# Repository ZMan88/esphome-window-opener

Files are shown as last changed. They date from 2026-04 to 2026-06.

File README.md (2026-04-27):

# Window Opener

A DIY ESP32-based device that opens and closes a European tilt-and-turn window, integrated with Home Assistant via ESPHome. One actuator anchored at the bottom-hinge corner of the frame drives both tilt and turn modes, controllable as a percentage (0–100%).

**Status:** scaffolding (Phase 0). No hardware built yet. See `PLAN.md`.

If you're trying to understand what this thing physically *looks like*, start with [`docs/how-it-works.md`](docs/how-it-works.md) — plain-language walkthrough plus an annotated 3D overview.

Assembly overview — installed mechanism
Mounting geometry — front view, tilt mode, turn mode

## How it works

A tilt-and-turn window has one corner — the bottom-hinge-side corner — that stays fixed in both tilt mode (short inward tilt from the top) and turn mode (full inward swing like a door). Anchoring one end of a linear actuator at that fixed corner and the other end at the opposite sash corner means the same stroke drives both modes. The user picks the mode on the window handle; the firmware only commands position.

## Hardware (at a glance)

- **MCU:** ESP32 DevKit V1
- **Actuator (choose one at build time):**
  - 12V DC linear actuator + BTS7960 H-bridge (robust, simple)
  - NEMA17 stepper + TMC2209 + lead screw (silent, precise)
- **Power:** 12V PSU → buck to 5V for the ESP32
- **Feedback:** time-based position (with optional 10-turn pot) or step counting

Full BOM: [`hardware/BOM.md`](hardware/BOM.md). Wiring: [`hardware/wiring/`](hardware/wiring/).

## Quick start (firmware)

```
cp firmware/common/secrets.example.yaml firmware/common/secrets.yaml
# edit secrets.yaml with Wi-Fi + OTA creds
esphome run firmware/window-opener.yaml
```

Home Assistant auto-discovers the ESPHome device and exposes `cover.window_opener`.

## Repository map

- [`firmware/`](firmware/) — ESPHome YAML
- [`hardware/`](hardware/) — BOM, wiring, power
- [`mechanical/`](mechanical/) — CAD and 3D-print STLs
- [`home-assistant/`](home-assistant/) — example automations and Lovelace card
- [`docs/`](docs/) — architecture, assembly, calibration
- [`PLAN.md`](PLAN.md) — roadmap, decisions, open questions
- [`CLAUDE.md`](CLAUDE.md) — guidance for Claude Code sessions

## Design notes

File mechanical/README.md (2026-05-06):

# Mechanical design

The mechanical design is the load-bearing part of this project — the firmware only works if the geometry works. Read this before opening CAD.

## Mounting geometry

The target window (see `docs/window-spec.md`) is a European tilt-and-turn, 845 × 1325 mm, hinge on the **right**, handle on the **left**. The actuator is mounted horizontally across the top of the window:

- **Fixed end** at the **top-middle of the frame** (`x = W/2 = 422.5 mm` from the left jamb), on `cad/frame-bracket.FCStd`.
- **Moving end** on the **top edge of the sash**, `d = 120 mm` from the hinge side (`cad/sash-bracket.FCStd`).
- Both ends use **M6 or M8 ball-joint rod ends** so the actuator can swing vertically (tilt) and horizontally (turn) without binding.

Geometry — front, tilt, turn views

### Fixed-end mounting detail

The fixed-end bracket bolts to the **room-side (inside) face of the top frame rail**, not above the frame. The actuator body hangs in the room at roughly the height of the top of the window, with no interference from the ~20 mm ceiling gap above the frame.

Mounting cross-section — fixed end
Mounting cross-section — sash end

Both brackets are **190 mm wide** along the window length (into the page of the side cross-sections). That width sets the VHB + screw area available to resist torque from the actuator.

**Fixed-end bracket (top-middle of frame):**

- Hard constraint — only 20 mm of frame face is accessible. The sash covers the frame's inside face everywhere except a 20 mm strip between the sash top and the ceiling.
- The **frame top touches the ceiling** (no air gap above the frame), so there is nowhere to hook over. Mounting has to live in the 20 mm strip itself.
- **Load is comfortable.** Actuator force is along the window width, so peel bending is about the vertical axis across the full 190 mm plate width — not across the 18 mm plate height. Peel stress at stall ≈ 140 kPa, well inside standard VHB's 500 kPa limit (~3× margin).
- The `cad/frame-bracket.scad` bracket includes a 2 mm **ceiling-jam tab** at the top edge. It is an **install aid and a passive peel-resist** for edge cases (VHB aging, assembly errors) — *not* a primary load path. When the bracket is pushed up during install, the tab compresses slightly against the ceiling and holds the bracket in place while the VHB sets and screws go in.
- Load path: VHB (primary, shear + peel) → 2× M4 self-tappers into PVC (backup).
- Install: press the bracket up into the 20 mm strip (tab compresses), then screw in from the room side.

**Sash-end (moving) bracket — `docs/mounting-detail-sash.svg`:**

- The sash's room-side face is 20 mm proud of the frame, so the *entire* sash top rail is accessible.
- Plate is 190 × ~42 mm (~8000 mm²). Stall-force tensile stress ~160 kPa — 3× margin below VHB's limit. **No hook needed.**
- The 20 mm sash lip already provides most of the standoff the fixed-end bracket gets from its arm. The M6 rod-end shank threads directly through the plate; a nut on the sash side locks it. No separate arm geometry.
- Load path: VHB (primary) → 3× M4 self-tappers into the sash top rail.
- Install: peel-off VHB backing, press on, screw in. Much simpler than the fixed end.

### Why this geometry works for both modes

For an actuator to drive a rotation, neither endpoint can sit on the rotation axis — otherwise the distance between the two endpoints stays constant during rotation, and the actuator can't change the angle.

| Endpoint | On tilt axis (bottom edge)? | On turn axis (right edge)? |
|---|:-:|:-:|
| Fixed: top-middle of frame `(W/2, 0)` | off | off |
| Moving: top of sash, 120 mm from hinge `(W-120, 0)` | off | off |

Both endpoints are off both axes, so extending the actuator drives the sash open in whichever mode the handle has selected.

### Stroke–angle map (with d = 120 mm)

| State | Distance | Stroke |
|---|---:|---:|
| Closed | 302.5 mm | 0 |
| Full tilt (7°, scissor stop) | 343.1 mm | 40.6 mm |
| Full turn (90°) | 439.2 mm | 136.7 mm |
| Full turn (100°, hardstop margin) | 458.8 mm | 156.3 mm |

Target actuator: **200 mm stroke, ≥ 500 N force, 12 V DC.** Force is dominated by the turn-mode moment arm (`d = 120 mm`); tilt is gravity-assisted and needs < 20 N.

## Mode asymmetry — important

Full tilt sits at ~26% of stroke; full turn at ~78%. The same `cover.position = 50` means different window angles in the two modes. The firmware exposes raw **stroke %**; per-mode semantics live in Home Assistant (see `docs/architecture.md`). If you ever add a handle-position sensor, the firmware can remap to clean per-mode percentages — noted in `PLAN.md`.

## Ball-joint rod ends are required

In tilt mode the moving end traces a short arc around the bottom edge. In turn mode the same point traces a wide arc around the hinge side — a different plane. The actuator body must be free to swing in **two axes** at each end. Use **M6 or M8 rod-end (heim) joints** at both ends. Fixed pivots or single-axis hinges will bind in one mode, usually turn.

## Bracket design notes

- **Print in PETG or ABS**, not PLA — summer sun on the frame easily exceeds PLA's glass-transition temperature.
- Brackets mount with **VHB double-sided tape** as a reversible baseline; add self-tapping screws only after placement is confirmed (drilling into a PVC window is irreversible).
- The **tilt stay** (scissor visible in the top-left of `docs/window-photo.jpg` for the target window) lives on the handle side — keep brackets clear of its travel.
- The fixed-end bracket is on the top rail of the frame, centered. Leave ~20 mm clearance above so the actuator body can pivot up (retract side) and down (extend side) as the sash tilts.
- The sash bracket sits on the top rail of the sash, 120 mm inboard from the hinge. In turn mode it swings outward into the room; confirm nothing on the room side (curtains, blinds, shelves) is in the 90° arc.

## CAD files

- `cad/common.scad` — shared parameters (window dims, KP08 / Prusa-nut / NEMA17 dimensions).
- `cad/sash-bracket.scad` — moving-end window bracket, 120 mm from the hinge on the sash top rail.
- `cad/frame-bracket.scad` — fixed-end window bracket, top-middle of the frame.
- `cad/rig-motor-mount.scad` — lead-screw rig: motor + KP08 #1 + frame-side rod-end mount.
- `cad/rig-far-bearing.scad` — lead-screw rig: KP08 #2 holder at the far end.
- `cad/rig-carriage.scad` — lead-screw rig: Prusa-nut + LH rod-end carriage that slides on the screw.
- `cad/README.md` — install / render / print instructions.
- `stl/*.stl` and `stl/*.png` — exported printable STLs and preview renders.

### Window-side brackets

| Bracket | Preview |
|---|---|
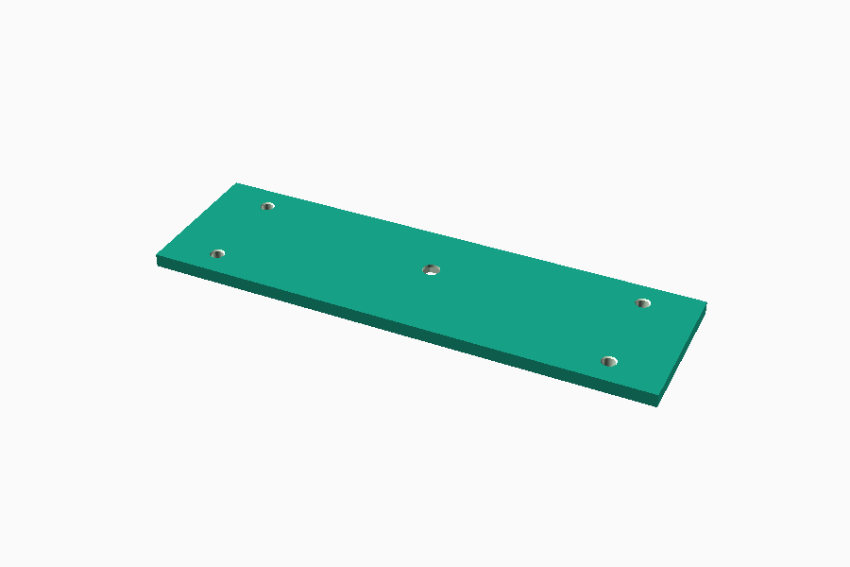
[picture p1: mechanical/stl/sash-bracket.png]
sash bracket
| Sash bracket (flat plate, 4 corner M4 + central M6 + back-face hex pocket) |  |
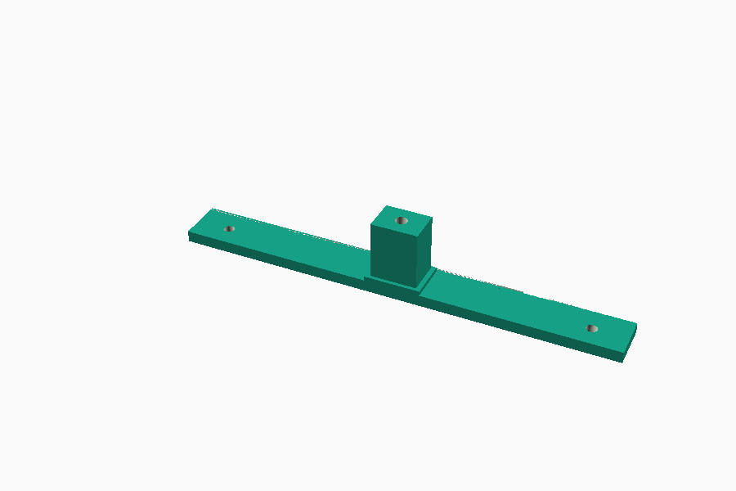
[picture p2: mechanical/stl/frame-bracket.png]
frame bracket
| Frame bracket (plate + arm + ceiling-jam tab) |  |

### Lead-screw rig (the "DIY linear actuator" between the two brackets)

| Part | Preview |
|---|---|
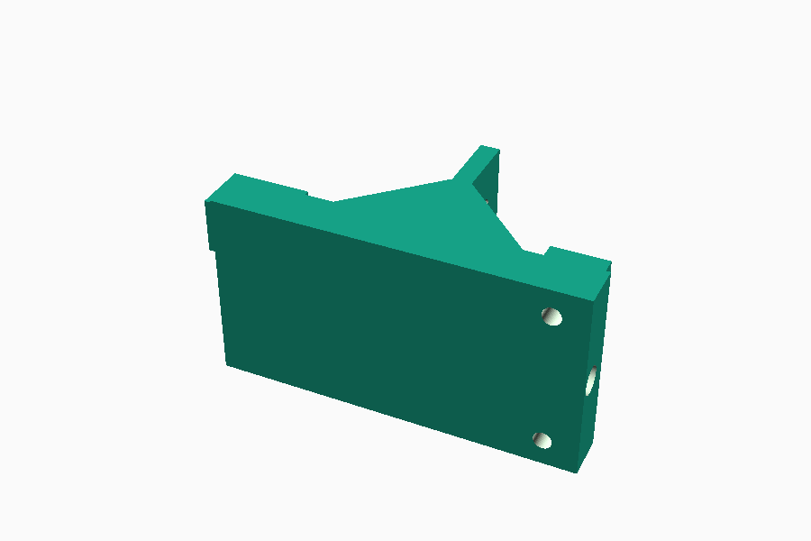
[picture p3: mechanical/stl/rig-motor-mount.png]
motor mount
| Motor mount + KP08 #1 holder + rod-end tab |  |
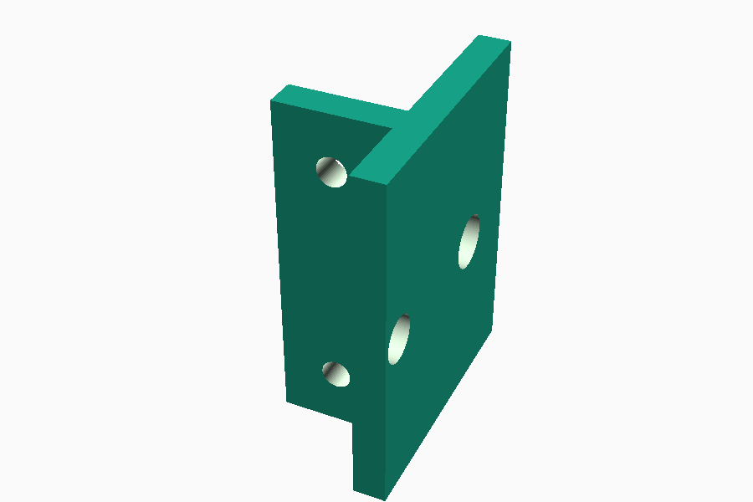
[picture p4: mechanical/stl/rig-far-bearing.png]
far bearing
| Far-end bearing block |  |
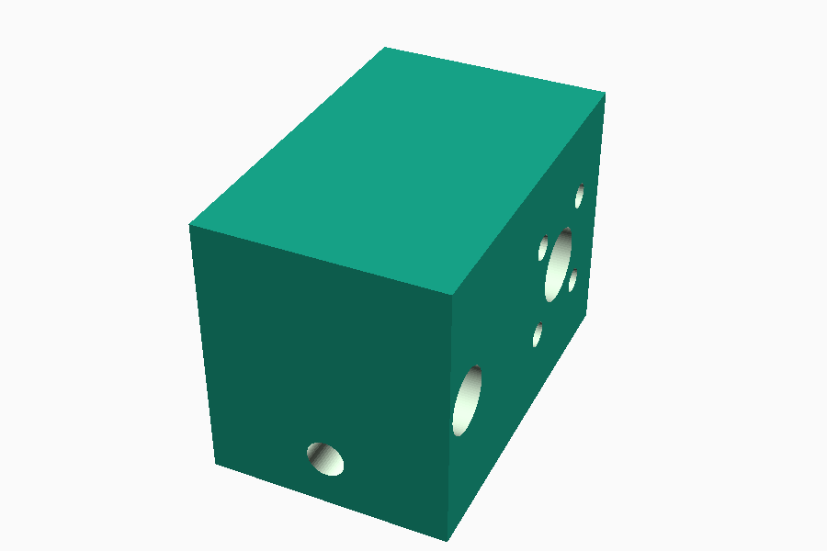
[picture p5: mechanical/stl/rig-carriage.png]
carriage
| Carriage (holds Prusa nut + LH rod-end) |  |

The rig is a self-contained linear-actuator equivalent: NEMA17 at one end drives the lead screw through KP08 #1, the screw extends to KP08 #2 at the far end, and the carriage rides along the screw via the Prusa nut. An 8 mm smooth steel rod runs parallel to the screw at a 30 mm offset to prevent the carriage from rotating with the screw — the carriage has a clearance hole through it for that rod. The motor-end of the rig has a rod-end tab that mounts to the frame bracket, and the carriage has its own rod-end mount on the bottom that connects to the sash bracket.

**Critical: rig CAD uses placeholder dimensions for the KP08 and Prusa nut at the top of `cad/common.scad`.** Verify with calipers before printing — those parts vary between manufacturers. Re-render after any `.scad` change.

Enclosure (`cad/esp32-enclosure.scad`) is not yet modelled — comes after the electronics bring-up in Phase 1.

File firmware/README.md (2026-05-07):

# Firmware

ESPHome config for the window opener. Entry point: `window-opener.yaml`.

## First-time setup

```
cp common/secrets.example.yaml common/secrets.yaml
# edit common/secrets.yaml with real values
```

Generate a fresh API encryption key and OTA password:

```
openssl rand -base64 32   # api_encryption_key
openssl rand -base64 16   # ota_password, fallback_password
```

## Build / flash

Run from the repo root, not from `firmware/`:

```
esphome config firmware/window-opener.yaml   # validate YAML only
esphome run    firmware/window-opener.yaml   # compile + flash + follow logs
esphome logs   firmware/window-opener.yaml   # tail logs from a running device
```

`esphome run` auto-detects USB vs OTA — plug in over USB the first time, then subsequent flashes go over the network.

## Switching actuator variant

Edit the `packages:` block in `window-opener.yaml`:

```yaml
packages:
  base: !include common/base.yaml
  variant: !include variants/linear-actuator.yaml   # or variants/stepper.yaml
```

Only one `variant:` line should be uncommented. Both variants expose the same HA entity (`cover.window_opener`), so no HA-side change is needed when switching.

## File layout

- `window-opener.yaml` — top-level config, variant selector
- `common/base.yaml` — Wi-Fi, API, OTA, logger, uptime
- `common/secrets.example.yaml` — template for `secrets.yaml`
- `variants/linear-actuator.yaml` — BTS7960 + time-based cover
- `variants/stepper.yaml` — TMC2209 + stepper + endstop + template cover (basic STEP/DIR, no UART)
- `variants/stepper-uart.yaml` — TMC2209 over **UART**: software-set current, live current/load/temperature exposed to HA, optional StallGuard sensorless homing. Requires two extra wires (XIAO D6 → driver RX, XIAO D7 → driver TX) and the slimcdk community external component.

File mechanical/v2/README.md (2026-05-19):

# Window Opener — v2 (motor on sash, screw on frame)

Variant of the v1 design with the actuator topology inverted: the
motor lives on the moving sash, the lead screw is anchored to the
static frame. Driving the motor rotates the screw, which threads
through a captive nut on the frame, pulling the motor (and the sash)
along with it.

v1 (in `mechanical/cad/`) remains the reference design; v2 explores
whether the inversion buys fewer parts and a simpler kinematic chain
at the cost of cable management and an exposed screw.

## How it works

```
   sash bracket                                            frame bracket
   ┌────────────┐  U-joint   ┌──────────────────────┐    ┌──────────────┐
   │ NEMA17     ├──[ ✕ ]─────┤ Tr8x8 lead screw ████├────┤ brass nut    │
   │ rigidly    │            │ rotates with motor   │    │ in 2-DOF     │
   │ on bracket │            └──────────────────────┘    │ gimbal       │
   └────────────┘                                        └──────────────┘
        │                                                       │
   bolted to sash                                          bolted to frame
   top rail at d=120 mm                                    top-middle
```

Motor spins the screw via a small U-joint. The screw passes through a
brass nut held in a 2-DOF gimbal on the frame bracket. The nut is
rotationally locked by the gimbal but free to pivot in pitch and
yaw — so the screw can swing through the angle range the sash
demands (tilt: arc in the X-Y plane; turn: arc in the X-Z plane)
while still translating through the threads.

When the motor turns clockwise the screw threads INTO the nut → screw
+ motor + sash get pulled toward the frame. Counter-clockwise →
pushed away.

## Components

| # | Part | Source |
|---|---|---|
| 1 | NEMA17 motor (LDO 42STH48-1684MAC) | reused from v1 |
| 2 | Tr8x8 lead screw, ~500 mm | reused from v1 (longer; see stroke notes) |
| 3 | Prusa MK3 brass nut | reused from v1 |
| 4 | Ø5–Ø8 single Cardan U-joint, L=35 mm, OD=14 mm | QUARKZMAN / Aopin pin-and-block style, 45° max angle, 2× M4 set screws per bore. Listing: Amazon DE `B0DTTRBWLK` (QUARKZMAN, 2-pack with wrench and spare grub screws). Equivalent Amazon US `B08V92X8M8` (Aopin). |
| 5 | Cross pins for gimbal (Ø3 × 25 mm) | sourced (steel dowel) |
| 6 | sash-motor-mount | printed — `cad/sash-motor-mount.scad` |
| 7 | frame-nut-gimbal | printed — `cad/frame-nut-gimbal.scad` |

What's gone vs v1: rig-motor-mount, rig-far-bearing, rig-carriage, 2×
KP08 pillow blocks, anti-rotation rod, both rod-ends. v2 needs 2
printed parts where v1 needed 5.

## Mechanical considerations

**Cantilevered motor.** NEMA17 ≈ 280 g hangs off the sash bracket's
M3 mounting holes. The bracket has a small "floor" that the motor
body rests on (mirror of v1's rig motor mount) so the four M3 bolts
don't carry the full bending moment.

**Exposed lead screw.** Most of the screw's length is in free air
between the brackets. A flexible sleeve over the screw (corrugated
plastic, cable-management style) is recommended for dust + accidental
contact.

**Motor cable on the moving part.** Cable runs from the controller
(static, on the frame or wall) to the motor (moving, on the sash).
Needs strain relief at the bracket and slack management through the
sash's motion range — a small drag chain or a service loop pinned at
the hinge corner is usually enough.

**Gimbal anti-roll.** The brass nut MUST be rotationally locked
relative to the frame bracket. If the nut can spin freely with the
screw, no axial translation happens. Both gimbal pins are perpendicular
to the screw axis, so they prevent roll while allowing pitch + yaw.

**Stroke length.** Effective max screw-to-anchor distance under full
tilt is ≈ 450 mm (see `docs/window-spec.md`); under 90° turn it's
≈ 440 mm. Use a 500 mm screw with the nut at mid-travel when closed,
giving ~150 mm of stroke each way.

## Range of motion at the gimbal

| Mode | Frame-to-sash anchor angle change |
|---|---|
| Closed → full tilt (~15°) | screw pitch + yaw both vary, max ~25° from horizontal |
| Closed → 90° turn | screw yaw varies by ~25° in the horizontal plane |

A 2-DOF gimbal with ±30° pin clearance handles both, and the
sourced 45°-max U-joint covers the motor-shaft side with ~20°
headroom.

## U-joint install notes

- **Motor end (5 mm bore):** seat both M4 set screws on the LDO 42STH48's
  D-flat (15 mm long × 4.5 mm deep, declared in `common.scad`). Loctite
  blue on the threads — the joint sees full motor torque and constant
  vibration.
- **Lead-screw end (8 mm bore):** Tr8 has no flat. File a small flat
  (~6 mm × 0.3 mm) on the smooth end-section of the screw for the
  set screws to bite. Loctite there too.
- **Backlash:** budget 1–2° of rotational play in the joint. At the
  Tr8 lead this is < 0.05 mm of axial slop — invisible at the percent
  resolution the HA `cover` entity exposes.
- **Velocity-ratio variation:** a single Cardan introduces ±10% RPM
  ripple at 25° angle. Irrelevant for a slow window cover, but if
  position holding ever feels jittery at the extremes, the upgrade is
  a double-Cardan or a constant-velocity joint of the same family.

## Render

```
cd mechanical/v2/cad
openscad --export-format binstl -o ../stl/sash-motor-mount.stl  sash-motor-mount.scad
openscad --export-format binstl -o ../stl/frame-nut-gimbal.stl  frame-nut-gimbal.scad
openscad --colorscheme=Nature --imgsize=900,600 -o ../stl/sash-motor-mount.png sash-motor-mount.scad
openscad --colorscheme=Nature --imgsize=900,600 -o ../stl/frame-nut-gimbal.png frame-nut-gimbal.scad
openscad --camera=350,-350,500,250,0,-15 --imgsize=1600,900 --colorscheme=Tomorrow \
         -o ../stl/v2-assembled-iso.png  v2-assembled.scad

# Single mesh STL of the whole assembly (viewing aid, not for slicing —
# the hardware stand-ins for motor / U-joint / screw / nut are baked in)
openscad --export-format binstl -o ../stl/v2-assembled.stl v2-assembled.scad
```

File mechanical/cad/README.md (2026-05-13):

# CAD

Parametric OpenSCAD sources for the two brackets. Text-based so the
geometry is diffable in git.

## Files

- `common.scad` — shared parameters (hole sizes, bracket width, etc.).
  Edit here to update both brackets at once.
- `sash-bracket.scad` — moving-end bracket, attaches to the sash top rail.
- `frame-bracket.scad` — fixed-end bracket, attaches to the 20 mm strip of
  frame face between the sash top and the ceiling.
- `rig-motor-mount.scad` — printed L-bracket carrying the NEMA17 + KP08 #1.
- `rig-far-bearing.scad` — printed L-bracket carrying KP08 #2 + anchor for
  the anti-rotation rod.
- `rig-carriage.scad` — printed block riding on the lead screw via the
  Prusa MK3 brass nut; holds the LH M6 rod-end on its bottom face.
- `rig-assembled.scad` — **assembly preview**. Includes the parts above
  plus stylised stand-ins for the motor / screw / KP08 / brass nut / rod-ends.
  Render with the camera invocations below to get the three views in
  `../stl/rig-assembled-{top,side,iso}.png`. The standalone parts'
  STLs/PNGs remain the source-of-truth for slicing.

## Install OpenSCAD

macOS: `brew install --cask openscad`  ·  [download page](https://openscad.org/downloads.html)

## Render STLs

```
cd mechanical/cad
openscad --export-format binstl -o ../stl/sash-bracket.stl  sash-bracket.scad
openscad --export-format binstl -o ../stl/frame-bracket.stl frame-bracket.scad
```

`--export-format binstl` emits binary STL (`~30–130 KB`) instead of
ASCII (`~10× larger`). Sliced STLs from the same `.scad` will be
identical between machines.

Optional preview render (PNG, no slicer needed):

```
openscad --colorscheme=Nature --imgsize=900,600 -o ../stl/sash-bracket.png  sash-bracket.scad
openscad --colorscheme=Nature --imgsize=900,600 -o ../stl/frame-bracket.png frame-bracket.scad
```

## Assembled view

```
cd mechanical/cad
# Top  (orthographic, looking straight down)
openscad --camera=150,800,0,150,-25,0   --imgsize=1600,500 --colorscheme=Tomorrow --projection=ortho \
         -o ../stl/rig-assembled-top.png  rig-assembled.scad
# Side (orthographic, looking along the rig's depth axis)
openscad --camera=150,-25,800,150,-25,0 --imgsize=1600,650 --colorscheme=Tomorrow --projection=ortho \
         -o ../stl/rig-assembled-side.png rig-assembled.scad
# Isometric (perspective)
openscad --camera=600,400,500,150,-25,0 --imgsize=1600,900 --colorscheme=Tomorrow \
         -o ../stl/rig-assembled-iso.png  rig-assembled.scad
# Single mesh of the whole rig (printable parts + hardware stand-ins)
openscad --export-format binstl -o ../stl/rig-assembled.stl rig-assembled.scad
```

The assembled STL is a visualization aid only — it includes the off-the-shelf
stand-ins (motor, screw, KP08s, nut, rod-ends) and is not meant for slicing.
For printing, use the individual part STLs (`rig-motor-mount.stl`, etc.).

The repo ships with the current STLs and PNGs in `mechanical/stl/`;
re-render after any change to the `.scad` sources.

> **macOS note:** the default `brew install --cask openscad` ships an
> Intel-only build that fails Gatekeeper on Apple Silicon. Use
> `brew install --cask openscad@snapshot` instead — it's the
> dev/nightly build with native Apple Silicon support.

## Print settings (starting point)

- Filament: PETG or ABS (don't use PLA — sun on the window frame can
  exceed its glass-transition temperature).
- Layer: 0.2 mm.
- Walls: 4 perimeters.
- Infill: 40 % gyroid.

### Orientation

- **`frame-bracket.scad`** — flat on the bed, **back face (VHB side) down**.
  The arm prints upward, no supports needed.
- **`sash-bracket.scad`** — flat on the bed, **back face UP**.
  The hex pocket for the M6 nut is on the back face; printing back-up
  means the pocket prints as a clean cavity. The M4 holes go all the
  way through, so orientation does not affect them.

## Post-print

- **Frame bracket:** tap the M6 hole at the end of the arm with an M6 ×
  1.0 hand tap. The hole is printed at 5.0 mm (tap-drill size).
- **Sash bracket:** *no tapping*. The M6 hole is a clearance through-hole
  (6.5 mm). The rod-end shank passes through and is locked with an M6
  nut sitting flush in the hex pocket on the back face.
- Apply VHB tape (3M 4950 or 5952) to the back face of both brackets
  before installing.
- Attach with M4 × 16 self-tappers into the PVC after positioning.

### Sash bracket — rod-end mounting in detail

Standard M6 male rod-ends usually have a 30 mm threaded shank. After:

1. drop the M6 nut into the hex pocket on the bracket's back face,
2. pass the rod-end shank through from the front,
3. thread it down into the nut and tighten,

…the tail of the shank will protrude ~20 mm past the back of the bracket.
You'll need to **drill a Ø6.5 × 25 mm pilot hole into the sash top rail**
where the shank tail will sit. PVC sash profiles have hollow chambers
inside, so you're drilling into air — no problem.

If you'd rather avoid drilling the sash, source a **short-shank rod-end**
(15–20 mm thread) instead; the tail then ends inside the bracket plate.

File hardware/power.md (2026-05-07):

# Power design

Single 12V mains PSU powers both the actuator and the ESP32. The ESP32 runs from 5V via a buck converter on the same 12V rail.

## Sizing the PSU

- **Linear actuator variant.** Size to roughly 1.5× the actuator's stall current. A typical 150 N / 50 mm-s actuator stalls at ~3 A, so a 5 A / 12 V / 60 W PSU is a safe baseline. Verify against the specific actuator's datasheet before ordering.
- **Stepper variant.** NEMA17 at 1.5 A/coil with both coils energised ≈ 3 A peak, but TMC2209 chopper drops typical draw well below that. A 3 A / 12 V / 36 W PSU is usually fine; go to 5 A if you're running near the stepper's rated current.

Headroom matters more than efficiency — the 12V rail also feeds the ESP32 buck.

## Protection

- **5 A inline blade fuse** on the 12V+ lead out of the PSU, close to the PSU (not close to the driver). Motor fault or stuck carriage should pop the fuse, not melt wires.
- **TVS diode (1.5KE18CA or similar)** across the actuator motor leads to snub inductive flyback. Linear actuator variant only — TMC2209 handles its own flyback.
- **100 µF electrolytic cap** across `VM`/`GND` at the TMC2209. Stepper variant only — *required*, not optional.
- The XIAO buck converter (MP1584 mini, or LM2596 if you prefer the bigger module) is fed from the same 12V rail, after the fuse. If the fuse blows, the XIAO loses power too — this is intentional so HA flags the outage.

## Grounding

All grounds (PSU −, driver GND, ESP32 GND, endstop GND) tie together at a single star point at the PSU. Do **not** daisy-chain grounds through the driver — motor return currents on a shared wire will introduce noise on the ESP32 GND.

## What's not here (yet)

- **No battery backup.** If mains drops, the window holds its last physical position. Intentional for v1.
- **No mains switch on the device.** Unplug the PSU if you need to service.
- **No opto-isolation** between ESP32 and driver. Both drivers referenced here are happy with direct 3.3V logic, but if you switch to a high-side driver or a 24V setup, add an isolator.

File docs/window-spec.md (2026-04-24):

# Target window — physical specification

These measurements drive the actuator sizing and bracket geometry. Re-measure if the build targets a different window.

| Reference | Photo |
|---|---|
| Front view, tilted | [`photos/window-tilted.jpeg`](photos/window-tilted.jpeg) |
| Looking up at the tilted gap | [`photos/bottom_up_view.jpeg`](photos/bottom_up_view.jpeg) |
| Right-side profile (hinge side, showing reveal) | [`photos/side_view.jpeg`](photos/side_view.jpeg) |

Observations from the photos:

- Frame profile is ~70 mm deep; room-side face is clean and accessible for bracket mounting.
- Wall reveal on the hinge side is ~15–20 cm — the sash has ample clearance to swing past 90° into the reveal in turn mode.
- Fly screen is on the **outside** of the sash; it does not constrain room-side mounting.
- Top-of-frame to ceiling gap is ~20 mm — irrelevant because the actuator mounts on the frame's room-side face, not above it.
- No tilt-stay (scissor) at the top-middle; the tilt limit is set by the hinges, leaving the top-middle clear for the fixed-end bracket.

## Measured

| Parameter | Value | Notes |
|---|---:|---|
| Sash width (W) | 845 mm | inside of frame, horizontal |
| Sash height (H) | 1325 mm | inside of frame, vertical |
| Tilt gap at top | 160 mm | distance from frame plane to sash face at full tilt |
| Turn gap at hinge side (at 90°) | 25 mm | sash-to-frame offset when fully turned |
| **Sash lip (room-side protrusion past frame)** | **20 mm** | the sash's room-side face sits 20 mm forward of the frame's inside face |
| **Sash thickness** | **80 mm** | full depth of the sash profile (outside face to room-side face) |
| **Frame depth** | **80 mm** | full depth of the frame profile |
| **Frame rail width (top, visible-plus-hidden)** | **80 mm** | total top-rail height from the outer edge to the inner edge; the sash covers 60 mm of this |
| **Frame face visible above sash** | **20 mm** | the sash covers the rest of the frame's inside face; bracket must fit in this 20 mm strip between sash top and ceiling |
| Hinge side | right | turn pivot axis = right edge |
| Handle side | left | mid-height |
| Tilt stay location | top-left (handle side) | visible in photo; mount clear of this |
| Turn hardstop | >90° | plan for ~100° headroom |

## Derived

| Derived quantity | Value | How |
|---|---:|---|
| Max tilt angle (θ_max) | ~7° | `arcsin(160 / 1325)` |
| Center of sash from turn pivot | 423 mm | `W / 2` |
| Sash weight (estimated) | 15–25 kg | double-glazed, PVC-framed, typical |

## Design constants used elsewhere in the repo

| Constant | Value | Where used |
|---|---:|---|
| `d` (moving-anchor offset from hinge) | 120 mm | `mechanical/README.md`, bracket CAD |
| Fixed anchor position | `(W/2, 0)` = top-middle of frame | `mechanical/README.md` |
| Moving anchor position | `(W - d, 0)` = top edge of sash, 120 mm from hinge | `mechanical/README.md` |
| Bracket width (both brackets) | 190 mm | along the window length, limits torque on mounting |

## Required actuator spec

| Parameter | Value | Reason |
|---|---:|---|
| Stroke | ≥ 160 mm (use 200 mm) | full-turn stroke plus margin |
| Force | ≥ 500 N | worst-case friction torque / moment arm at `d = 120 mm` |
| Voltage | 12 V DC | matches PSU choice |
| Speed | 15–25 mm/s | full stroke in 8–14 s (acceptable) |

## Stroke-to-angle table (for reference)

With `d = 120 mm`:

| Actuator stroke | Tilt angle | Turn angle |
|---:|---:|---:|
| 0 mm | 0° (closed) | 0° (closed) |
| 20 mm | ~5° | ~22° |
| 40 mm | ~7° (hardstop) | ~37° |
| 80 mm | — (stalled) | ~64° |
| 120 mm | — | ~84° |
| 137 mm | — | 90° |
| 160 mm | — | ~100° |

**Interpretation:** the same actuator stroke maps to different window angles depending on mode. Firmware exposes raw stroke %; HA automations translate to tilt or turn percentage if needed. See `docs/architecture.md`.

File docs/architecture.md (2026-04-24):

# Architecture

## Why one actuator drives both modes

A European tilt-and-turn window has two pivot axes that intersect at the bottom-hinge corner. That corner is the only point on the sash that **does not move** in either mode. Anchoring one end of a linear actuator at that corner and the other end at the diagonally-opposite sash corner means:

- In tilt mode: extending the actuator pushes the top of the sash inward (tilt opens).
- In turn mode: extending the actuator pushes the opposite side of the sash inward (turn opens).

The two arcs are in different planes, which is why both ends of the actuator need ball-joint rod ends — see `mechanical/README.md`.

The firmware is kept mode-agnostic: it commands a stroke position in 0–100 %. Whichever mode the user has selected on the window handle determines what that stroke does. This keeps the firmware, the HA integration, and the calibration data simple — one position scale, one `cover` entity.

## Software stack

```
Home Assistant
       │  (native ESPHome API, encrypted)
       ▼
     ESP32 ── ESPHome firmware (firmware/window-opener.yaml)
       │      - cover entity state machine
       │      - variant package (linear or stepper)
       ▼
  Motor driver ── Actuator
 (BTS7960 / TMC2209)
```

HA sees one entity: `cover.window_opener` with `position` 0–100. It does not know or care which actuator variant is flashed or which window mode the handle is in.

## Position tracking

- **Linear-actuator variant:** ESPHome's `cover.time_based` platform interpolates position from commanded duration. Cheap, no extra hardware. Drifts after repeated partial moves — full open/close periodically re-syncs the estimate. An optional 10-turn pot on GPIO35 upgrades this to closed-loop.
- **Stepper variant:** step counting after homing against a closed-side endstop. Exact, but the device reports `unknown` until the first homing sweep completes on boot.

## Safety model

- New movement commands pre-empt in-flight ones.
- Stall or obstruction → stop and hold. No auto-retry. HA surfaces the stuck state so a human can intervene.
- On boot: position unknown → HA cover state `unknown` → first command triggers homing.
- The window handle is the physical manual override. Turning the handle mid-travel doesn't hurt anything — the sash disengages from whichever pivot path it was on.

## What's explicitly out of scope for v1

- Battery backup.
- On-device pushbuttons.
- Rain / CO₂ sensors on the device itself (HA handles these).
- Multi-window coordination.
- Remote web UI outside of HA.

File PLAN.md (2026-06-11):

# Window Opener — Roadmap & Decision Log

## Context

DIY opener for a European tilt-and-turn window, ESP32 + ESPHome + Home Assistant. A single actuator anchored at the bottom-hinge-side corner drives both tilt (short arc) and turn (long arc) modes — the user pre-selects the mode via the window handle, the firmware commands only a 0–100% position. Tilt is the primary case; turn must work but is secondary.

## Locked decisions

- **MCU:** Seeed Studio XIAO ESP32-C6 — chosen for forward-compatibility with Matter / Thread later if desired, plus the smaller form factor
- **HA integration:** ESPHome, one `cover` entity with position 0–100 (native API; Matter is a future option)
- **Mounting:** fixed end at top-middle of frame, moving end on top edge of sash 120 mm from hinge, ball-joint rod ends at both ends
- **Actuator:** **stepper + lead screw** (Variant B) — committed late April 2026; parts ordered, see `docs/build-log.md`
- **Power:** 12V mains PSU → buck to 5V for the ESP32; no battery backup in v1
- **Manual override:** window handle (no device buttons in v1)

## Phases

- [x] **Phase 0 — Scaffolding.** Repo structure, docs, base firmware YAML, BOM, wiring templates. (This PR.)
- [x] **Phase 1 — Bench prototype.** ESP32 + driver + actuator on a bench jig. Home Assistant discovers `cover.window_opener`. % travel works against a dummy load. ✅ Passed 2026-05-08 with `variants/stepper.yaml` (basic STEP/DIR).
- [ ] **Phase 1.5 — UART upgrade (optional).** Add two wires to the driver, switch to `variants/stepper-uart.yaml`, verify current/load/temperature show up as HA sensors. Replaces the Vref pot with software current control.
- [ ] **Phase 2 — Tilt on real window.** Print brackets, mount on the frame, tune stroke calibration for tilt. Stall detection dialed in.
- [ ] **Phase 3 — Turn validation.** Verify the same mount drives turn mode without binding; measure max stroke actually used.
- [ ] **Phase 4 — Polish.** Safety edge cases, HA automations, Lovelace card, enclosure, OTA workflow.

## Decision log

Append entries as decisions get made. Format: `YYYY-MM-DD — decision — reason.`

- 2026-04-24 — Anchor actuator at bottom-hinge-side corner — single fixed point across both modes; one stroke drives both. **SUPERSEDED 2026-04-24** (see below).
- 2026-04-24 — Defer final actuator choice (linear vs stepper) to build time — dictated by parts availability, and ESPHome packages make the swap cheap.
- 2026-04-24 — Tilt takes priority over turn in firmware/UX trade-offs — tilt is the everyday ventilation case.
- 2026-04-24 — **Corrected mounting geometry: fixed end at top-middle of frame, moving end on top rail of sash 120 mm from hinge.** The earlier "bottom-hinge corner" plan was wrong: that point sits on both pivot axes, so the actuator distance is conserved in both modes — it couldn't actually drive anything. Both new endpoints are off both axes. Reason: kinematic analysis during design review.
- 2026-04-24 — Target window measured: W=845, H=1325, max tilt ≈ 7°, turn hardstop > 90°. See `docs/window-spec.md`.
- 2026-04-24 — Actuator spec: 12 V, 200 mm stroke, ≥500 N. Stroke driven by 90°+ turn; force by friction torque over a 120 mm moment arm.
- 2026-04-24 — Accept mode-asymmetry in firmware v1: `cover` reports raw stroke %, not per-mode %. Tilt full = ~26%, turn full = ~78%. HA handles mode semantics. A handle-position sensor could remap per mode later — not in v1.
- 2026-04-29 — Variant B (stepper + Tr8x8 lead screw) committed. Parts ordered (LDO 0.9° NEMA17, BIGTREETECH TMC2209 V1.3 ×2, KP08 ×2, Tr8x8 nuts ×3, lead screw 400 mm, 5→8 couplers, M6 rod-ends, LM2596). See `docs/build-log.md`.
- 2026-04-29 — **MCU swapped to ESP32-C6** (already in user's drawer). Kept ESPHome with native API for v1; the C6 keeps Matter/Thread on the table for a future migration. Required: framework switch from `arduino` to `esp-idf`, GPIO remap 25/26/27/34 → 4/5/6/7.
- 2026-05-06 — Specific board confirmed: **Seeed Studio XIAO ESP32-C6** (smaller than the DevKitC-1, only 11 GPIOs broken out). GPIO remapped 4/5/6/7 → 1/2/21/19, exposed as XIAO labels D1/D2/D3/D8. Pin assignment: D1=DIR, D2=STEP, D3=EN, D8=endstop.
- 2026-05-08 — Phase 1 bench-test passed (motor moves on command via HA). Added `variants/stepper-uart.yaml` for the UART-driven upgrade: motor current set in software, current/load/temperature surfaced as HA sensors, StallGuard available. The BTT V1.3 has buffered TX/RX (verified by multimeter — no continuity), so UART wires are direct cross-connection (XIAO D6 ↔ driver RX, XIAO D7 ↔ driver TX) with no series resistor needed.
- 2026-06-05 — **Firmware feature pass on `stepper-uart.yaml`** (now the active variant in `window-opener.yaml`):
  - **Closed detection via the window's own contact sensor imported from HA** (`closed_sensor_entity` substitution), not the printed D8 switch. The D8 endstop is **not installed at the moment** — its block is left commented, ready to OR back in. Reason: v2 mechanical has no carriage to mount the switch on yet, and the window already has a contact sensor. Trade-off: homing now depends on the HA connection.
  - **Lock** (`lock.window_lock`): drives fully closed then clamps at a firmer hold current (`lock_hold_current`, default 900 mA); refuses open/position commands while locked (closing still allowed). The manual handle remains the real mechanical lock. Lock state persists across reboot (re-homes then re-clamps on boot).
  - **Free-wheel** (`switch.window_freewheel`): releases the coils (`tmc2209.currents` `standstill_mode: freewheeling`, 0 mA hold) so the sash is hand-movable. (Avoids `tmc2209.enable/disable`, whose slimcdk `ActivationAction` fails to compile under ESPHome's 2026-04 TemplatableFn change.) Move-detection: a transition of the closed signal while free-wheeling marks position unknown → next command re-homes first. Limitation: a bare TMC2209 has no rotor feedback, so hand-movement that never crosses the closed sensor can't be detected (keeps last position). Encoder would fix this — deferred.
  - **Open-end** = StallGuard hard-stop (DIAG on D9): a stall while opening reports position = full stroke; a stall while closing is treated as an obstruction (stop + hold, no retry). Inert until SGTHRS is tuned in Phase 3.
  - **Switchable end-detection** (added 2026-06-06): `homing_mode: contact | sensorless` substitution (in `window-opener.yaml`). `contact` = home closed from the HA contact, open by calibrated step count (StallGuard = obstruction backstop). `sensorless` = no contact: ram closed at a gentle `homing_current` until StallGuard trips, and *learn* the open end from the opening-direction stall into a runtime `g_full_stroke`. Sensorless requires a tuned `stall_threshold` (SGTHRS > 0). Kept switchable so both can be compared on the real rig before committing — sensorless rams the stops every home (wear) and can't distinguish obstruction from end, so contact is the default/recommended. Position % is relative to `g_full_stroke` (fixed in contact, learned in sensorless — do one full open after homing to learn it).
  - **Homing**: passive on boot (no auto-motion — a power blip won't slam an open window shut). Position reads `unknown` until the closed contact reports shut (zeroes in place) or the first move triggers a homing sweep. Locked state is the exception: it actively drives closed on boot to re-clamp. CLAUDE.md "unknown until homed" invariant now actually enforced.

## Open questions

- License choice (placeholder MIT).
- 3D-print material for brackets — PETG vs ABS (sun/heat resistance).
- ~~Do we want an `esphome` `switch` for "home now" on boot, or keep homing fully automatic?~~ **Resolved 2026-06-05, revised 2026-06-11:** homing is automatic (passive on boot, and before any move when position is unknown). A manual **"Home now (drive to closed)"** button was added 2026-06-11 — `move_to` only auto-homes when position is unknown, so on-demand re-homing needed an explicit trigger.
- Free-wheel hand-movement that never crosses the closed sensor isn't detectable without rotor feedback — add a magnetic encoder (e.g. AS5600 on the screw) if per-mm position must survive manual moves. Deferred.
- Stall detection threshold — decide empirically in Phase 1.
- Handle-position sensor (reed switch) to detect tilt vs turn mode — if added, firmware can remap `cover.position` per mode for clean HA UX. Defer to v1.5.
- Exact sash weight — estimated 15–25 kg; confirm with a luggage scale before final actuator purchase.

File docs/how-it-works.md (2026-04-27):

# How it works — visual walkthrough

This page is the "I just want to picture the thing" guide. The other docs are the source of truth, this one is the orientation map.

## The 30-second version

You bolt **two small brackets** to the top of the window — one to the **frame** (which doesn't move), one to the **sash** (the part that swings). A **12 V linear actuator** stretches between them like an arm. When the actuator extends, it pushes the sash open. When it retracts, it pulls the sash closed. An ESP32 nearby drives the actuator and talks to Home Assistant.

That's the whole mechanism. Everything else is detail.

Isometric overview

## The pieces

There are only six things to get straight in your head:

| Piece | What it is | Where it lives |
|---|---|---|
| **The frame** | Doesn't move. The fixed border of the window. | Built into the wall. |
| **The sash** | Moves. Holds the glass. | Inside the frame opening; protrudes 20 mm into the room. |
| **Frame bracket** | Small 3D-printed plate (red in the diagrams) | Glued + screwed to the **room-side face of the frame**, top-middle. |
| **Sash bracket** | Same idea, slightly different shape | Glued + screwed to the **room-side face of the sash**, near the hinge (120 mm from the right edge). |
| **Actuator** | A 200 mm 12 V motorised piston. | Hangs horizontally between the two brackets, just in front of the top of the window. |
| **ESP32 box** | The brains | Mounted on the frame near the fixed bracket. Wires go to the actuator and to a 12 V power supply. |

## How the brackets connect to the actuator

Each bracket holds an **M6 rod-end** — a small ball-joint. The actuator's two ends bolt onto these rod-ends. Because both ends of the actuator can pivot freely (that's what "ball joint" means), the actuator can swing through the wide arcs that tilt and turn require without binding.

Picture it like an arm with shoulder joints at both ends.

## How tilt works

1. You turn the window handle to the **tilt** position.
2. The handle releases the side latches but keeps the bottom hinged.
3. From Home Assistant (or an automation), you say "tilt 50%".
4. The ESP32 commands the actuator to extend partway.
5. The actuator pushes the sash bracket forward.
6. Because the sash is hinged at the bottom, the **top of the sash swings inward** into the room — exactly like the photo you sent.

To close: the actuator retracts, pulls the sash back to flush, the gravity in the seal does the rest.

## How turn works

Same actuator, same brackets, different latch position on the handle:

1. You turn the window handle to the **turn** position (handle points sideways).
2. The handle releases the bottom hinge and engages the side hinges.
3. From Home Assistant, "turn 80%".
4. The actuator extends.
5. The sash bracket is near the hinge side, so a relatively short extension at that point swings the **opposite (handle) side of the sash into the room**, like opening a door.

The same actuator stroke does both because both anchor points were chosen carefully (`docs/geometry.svg` has the math) so neither anchor sits on a pivot axis. If either did, the actuator would jam in that mode.

## The most important constraint

The frame bracket has only **20 mm of frame face** to grab onto, because the sash protrudes 20 mm forward of the frame and covers everything below that strip. The bracket plate is therefore short and wide — 190 × 18 mm — and uses a **compressible tab** at the top that wedges against the ceiling during install. The sash bracket has the entire sash face to work with, so it's a bigger, simpler plate.

See:
- [`mounting-detail.svg`](mounting-detail.svg) — the frame bracket in cross-section
- [`mounting-detail-sash.svg`](mounting-detail-sash.svg) — the sash bracket in cross-section
- [`geometry.svg`](geometry.svg) — three views (front, tilt, turn) showing the macro layout

## How to read the existing diagrams

| Diagram | Drawing convention | Why it looks weird |
|---|---|---|
| `geometry.svg` panel 1 (Front) | Like a photo of the window from inside the room | This is the "normal" view — actuator is the diagonal grey bar |
| `geometry.svg` panel 2 (Tilt) | Vertical slice through the side, the wall is on the left | The actuator looks short because it's been rotated downward as the sash tilted |
| `geometry.svg` panel 3 (Turn) | View from above, looking down | The window opens away from the wall, into the room (downward in the diagram) |
| `mounting-detail.svg` | Vertical slice cut sideways through the top of the frame | "Outside" is on the left, "room" is on the right — the actuator body extends out of the page |
| `mounting-detail-sash.svg` | Same as above, but cut through where the sash bracket lives | The actuator body extends out of the page, going toward the fixed bracket |

## Order of build

Once parts arrive, the build order is:

1. **Bench-test the electronics first.** ESP32 + driver + actuator on the desk, no window. Confirm Home Assistant sees `cover.window_opener` and that "open" / "close" / "set position" actually move the actuator. (This is Phase 1 in `PLAN.md`.)
2. **Print both brackets** from `mechanical/cad/*.scad`. Tap the M6 holes.
3. **Dry-fit on the window.** Tape the brackets in position before any glue or screws — measure twice, drill once.
4. **Mount the actuator.** Screw the rod-ends onto the actuator first, then onto the brackets.
5. **Tilt-only first.** Run a few full tilt cycles before trying turn — turn has more inertia and a wider error margin.
6. **Calibrate.** `docs/calibration.md` covers this.

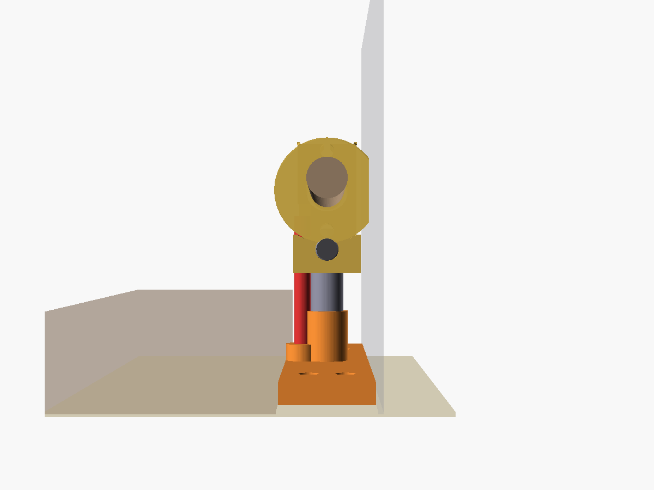
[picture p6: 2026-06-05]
mechanical/v2/cad/sketches/option3-side.png

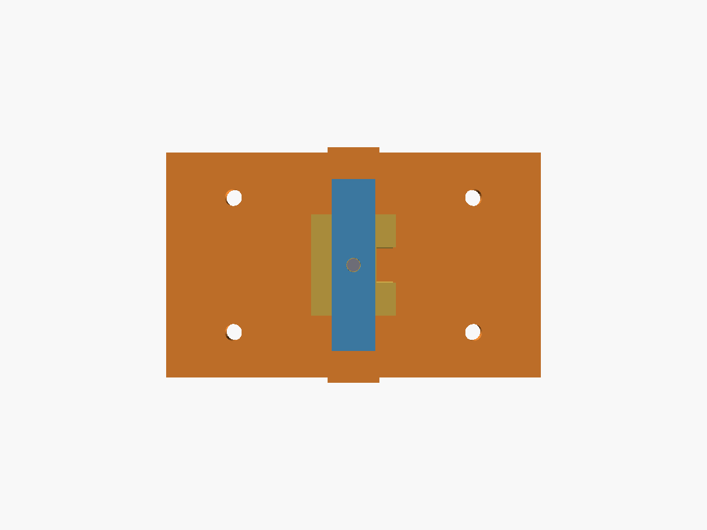
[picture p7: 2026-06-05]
mechanical/v2/stl/frame-nut-gimbal.png

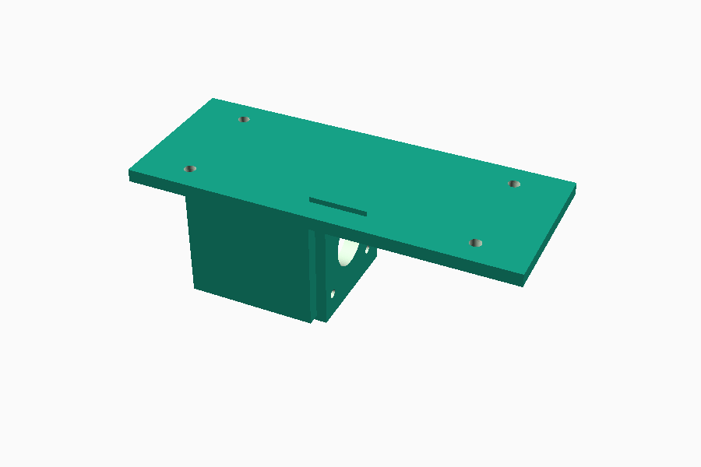
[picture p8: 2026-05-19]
mechanical/v2/stl/sash-motor-mount.png

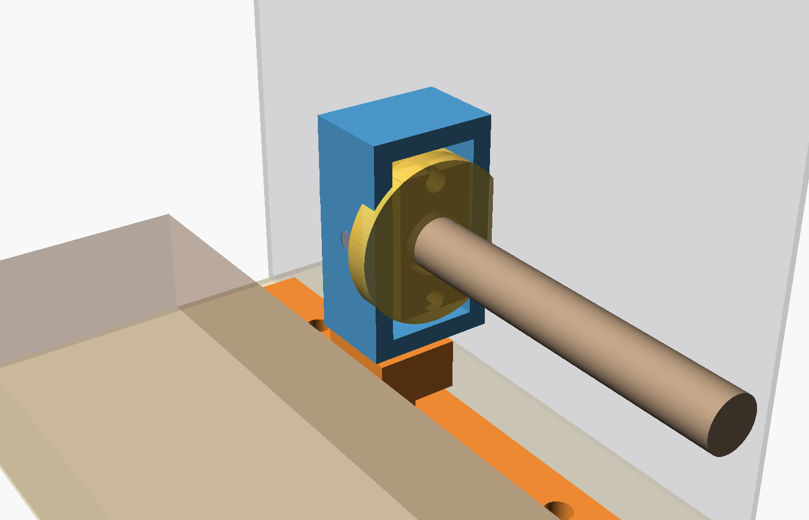
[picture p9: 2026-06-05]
mechanical/v2/cad/sketches/option1-zpivot.png

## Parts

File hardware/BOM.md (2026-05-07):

# Bill of Materials

Romanian online sources are listed first; international fallbacks (AliExpress, Amazon) where the part is uncommon locally. Prices are rough April 2026 estimates and should be re-verified at order time.

Pick **one** actuator track (Variant A or B), then add the common parts and the parts for that variant.

## Common to both variants

| Qty | Part | Source | ~RON | ~EUR |
|---:|---|---|---:|---:|
| 1 | **ESP32-C6 DevKitC-1** (Wi-Fi 6, BT 5 LE, Thread/Zigbee) | [optimusdigital.ro ESP32 boards](https://www.optimusdigital.ro/358-placi-cu-esp32) · AliExpress / Amazon for the official Espressif kit | 50–80 | 10–16 |
| 1 | 12V DC power supply, 60W / 5A, plastic case | [webled.ro YDS 60W](https://webled.ro/sursa-alimentare-yds-12v-5a-60w-cu-fir-carcasa-plastic/) · [led-box.ro 60W](https://led-box.ro/products/sursa-alimentare-5a-60w-12v) | 60–100 | 12–20 |
| 1 | DC-DC step-down buck 12V → 5V | **Recommended:** small MPS-based module (MP1584EN or similar, ~22 × 14 mm). [robofun.ro MP1584](https://www.robofun.ro/surse-de-alimentare/mp1584en-mini-lm2596-ultra-small-dc-dc-3a-power-step-down-adjustable-module-buck-converter-24v-turn-12v-9v-5v.html) · AliExpress. **Alternative:** [optimusdigital.ro LM2596 5A](https://www.optimusdigital.ro/en/adjustable-step-down-power-supplies/1109-lm2596-dc-dc-step-down-module-5a.html) — bigger but interchangeable. Either is fine; both run cool at our ~270 mA logic load. | 5–20 | 1–4 |
| 1 | Inline blade fuse holder + 5A fuse | [optimusdigital.ro fuse holders](https://www.optimusdigital.ro/ro/sigurante-fuzibile/) · auto parts shop | 10–15 | 2–3 |
| 1 | TVS diode 1.5KE18CA (linear-actuator variant only) | [optimusdigital.ro diode category](https://www.optimusdigital.ro/ro/77-diode) · AliExpress | 5–10 | 1–2 |
| 1 | M4 × 16 self-tapping screws (4–6 pcs) | hardware store / [emag.ro](https://www.emag.ro/) | 5–10 | 1–2 |
| 1 | 3M VHB tape (4950 or 5952), ~1 m × 19 mm | [emag.ro 3M VHB search](https://www.emag.ro/search/3M+VHB) · auto parts shop | 30–50 | 6–10 |
| 2 | M6 rod-end (heim joint), male, 50 mm shank | [emag.ro rod-end search](https://www.emag.ro/search/rod+end+m6) · AliExpress / Amazon.de — search "M6 rod end heim" | 25–50 | 5–10 |
| 1 | 3D-printed bracket set (2 pcs) | self-print from `mechanical/cad/*.scad` | filament cost | — |
| 1 | 3D-printed ESP32 enclosure | self-print (CAD pending Phase 1) | — | — |

## Variant A — 12V linear actuator (recommended for first build)

| Qty | Part | Source | ~RON | ~EUR |
|---:|---|---|---:|---:|
| 1 | **12V DC linear actuator, 200 mm stroke, 500 N, 20 mm/s** | [spy-shop.ro 200mm/500N](https://www.spy-shop.ro/actuator-liniar-pentru-cursa-de-200-mm-20-mm-s-12-vdc-500-n.html) · [emag.ro HS1471 series](https://www.emag.ro/search/actuator+liniar+12V+500N) | 250–400 | 50–80 |
| 1 | BTS7960 H-bridge module (43 A) | [optimusdigital.ro BTS7960](https://www.optimusdigital.ro/en/brushed-motor-drivers/174-bts7960-43-a-motor-driver.html) | 30–55 | 6–11 |
| 1 | (optional) 10-turn linear potentiometer for closed-loop position | [optimusdigital.ro potentiometers](https://www.optimusdigital.ro/ro/96-potentiometre-rezistente) · AliExpress | 25–40 | 5–8 |

Wiring: [`wiring/linear-actuator.md`](wiring/linear-actuator.md).

## Variant B — Stepper + lead screw

| Qty | Part | Source | ~RON | ~EUR |
|---:|---|---|---:|---:|
| 1 | NEMA17 stepper, ≥ 40 N·cm (e.g. 17HS19-2004S) | [optimusdigital.ro stepper category](https://www.optimusdigital.ro/ro/76-motoare-pas-cu-pas) · [emag.ro NEMA17](https://www.emag.ro/search/nema+17+stepper) | 50–100 | 10–20 |
| 1 | TMC2209 stepper driver | [optimusdigital.ro TMC2209](https://www.optimusdigital.ro/en/motor-drivers/13023-tmc2209-stepper-motor-driver.html) | 25–45 | 5–9 |
| 1 | T8 × 8 lead screw + brass nut, 300–500 mm | [piese3d.ro T8x8 400mm](https://piese3d.ro/surub-trapezoidal-400mm-t8x8-cu-piulita) · [reprapmania.ro lead screws](https://www.reprapmania.ro/catalog/suruburi-si-piulite-trapezoidale-398) | 40–80 | 8–16 |
| 1 | Flexible coupler 5 mm → 8 mm | [optimusdigital.ro couplings](https://www.optimusdigital.ro/ro/) · [reprapmania.ro](https://www.reprapmania.ro) | 10–20 | 2–4 |
| 2 | KP08 bearing blocks (or equivalent) | [reprapmania.ro](https://www.reprapmania.ro) · [piese3d.ro](https://piese3d.ro) · AliExpress | 15–30 | 3–6 |
| 1 | Normally-open micro-switch or reed + magnet | [optimusdigital.ro switches](https://www.optimusdigital.ro/ro/95-comutatoare-i-butoane) | 5–10 | 1–2 |
| 1 | 100 µF electrolytic cap (across TMC2209 motor supply) | [optimusdigital.ro caps](https://www.optimusdigital.ro/ro/68-condensatoare) | 1–3 | 0.20–0.60 |

Wiring: [`wiring/stepper.md`](wiring/stepper.md).

## Notes on sourcing

- **optimusdigital.ro** is the go-to Romanian hobbyist electronics shop — fastest delivery, most ESPHome-friendly parts in stock. Default first place to check for any electronic component.
- **spy-shop.ro / a2t.ro** carry ready-made 12V linear actuators in many stroke lengths (100, 200, 300, 500, 800 mm). The 200 mm / 500 N spec we want is mainstream — usually in stock.
- **piese3d.ro / reprapmania.ro** are 3D-printer parts shops; lead screws, couplers, and bearings live there. Lead times are usually 1–3 days within RO.
- **M6 rod-ends** are not commonly stocked at hobbyist electronics shops in RO. Easiest path: search `emag.ro` for "rod end m6" or order from AliExpress / Amazon.de (1–2 weeks delivery).
- **AC-DC 12V PSUs** are everywhere — LED supply shops (`webled.ro`, `led-box.ro`, `v-tac-led.ro`) usually beat electronics shops on price for the same MEAN-WELL-equivalent unit.
- **Currency:** ~5 RON ≈ 1 EUR in 2026. Optimus Digital lists in RON; AliExpress/Amazon in USD/EUR.

## Not included (yet)

- Rain sensor — v1 relies on HA weather integrations, not on-device sensing.
- Battery backup — v1 is mains-only.
- Device-side pushbuttons — v1 uses the window handle as manual override.

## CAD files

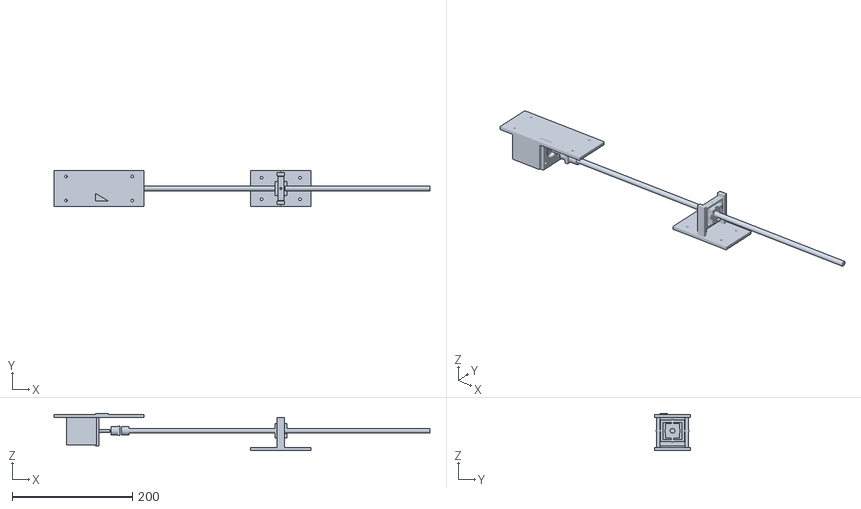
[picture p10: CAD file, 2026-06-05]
mechanical/v2/stl/v2-assembled.stl
625.0 x 60.0 x 62.1

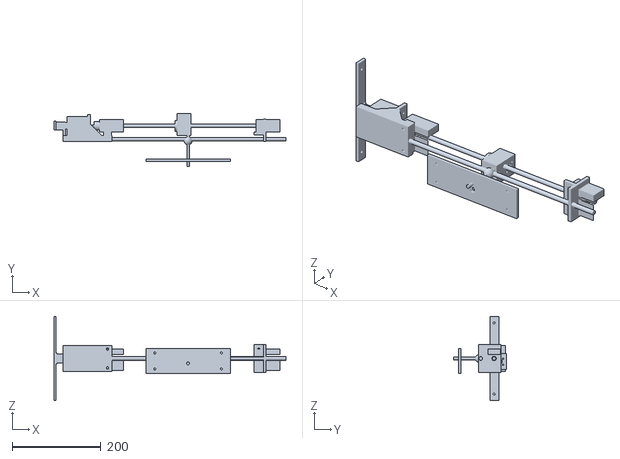
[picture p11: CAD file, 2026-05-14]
mechanical/stl/rig-assembled.stl
522.5 x 119.7 x 190.0

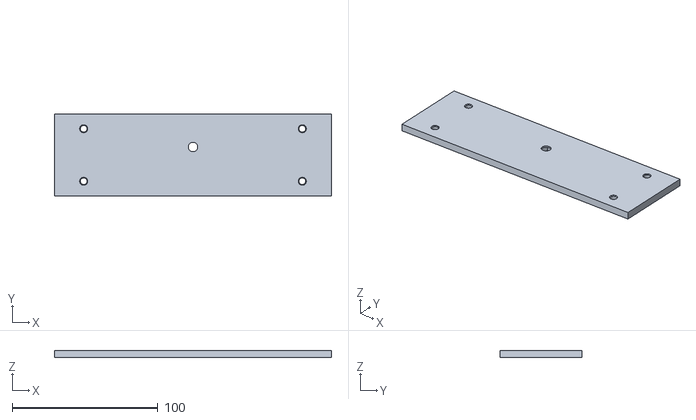
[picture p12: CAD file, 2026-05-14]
mechanical/stl/sash-bracket.stl
190.0 x 56.0 x 5.00

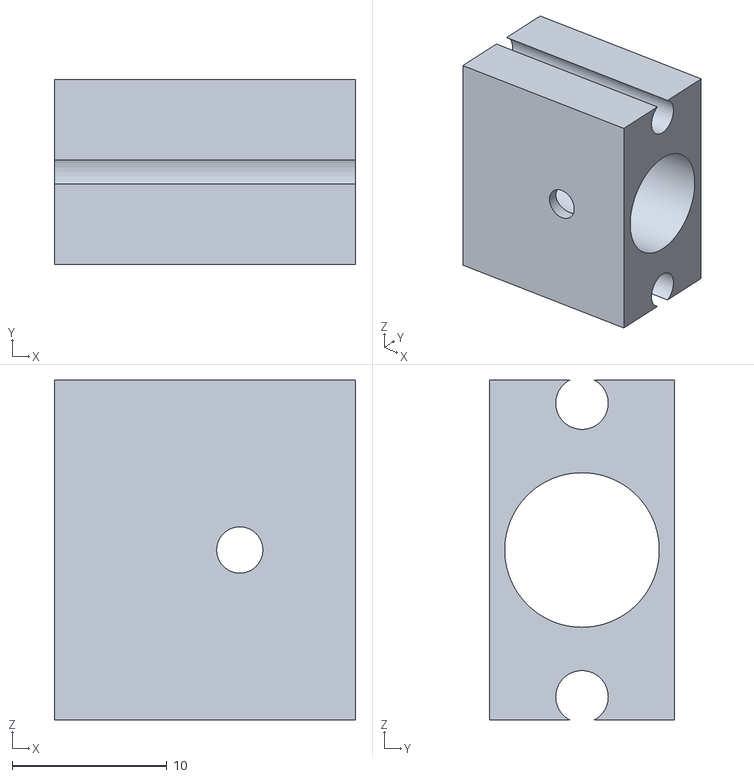
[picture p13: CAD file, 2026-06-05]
mechanical/v2/cad/sketches/option1-block.stl
19.5 x 12.0 x 22.0

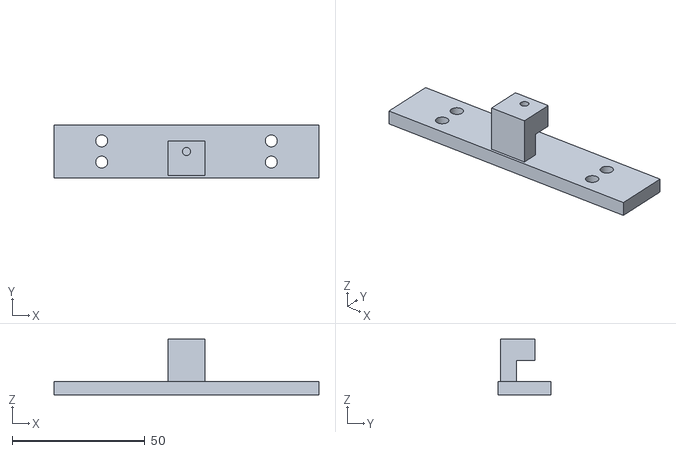
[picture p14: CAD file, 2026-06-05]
mechanical/v2/cad/sketches/option1-lbracket.stl
100.0 x 20.0 x 21.0

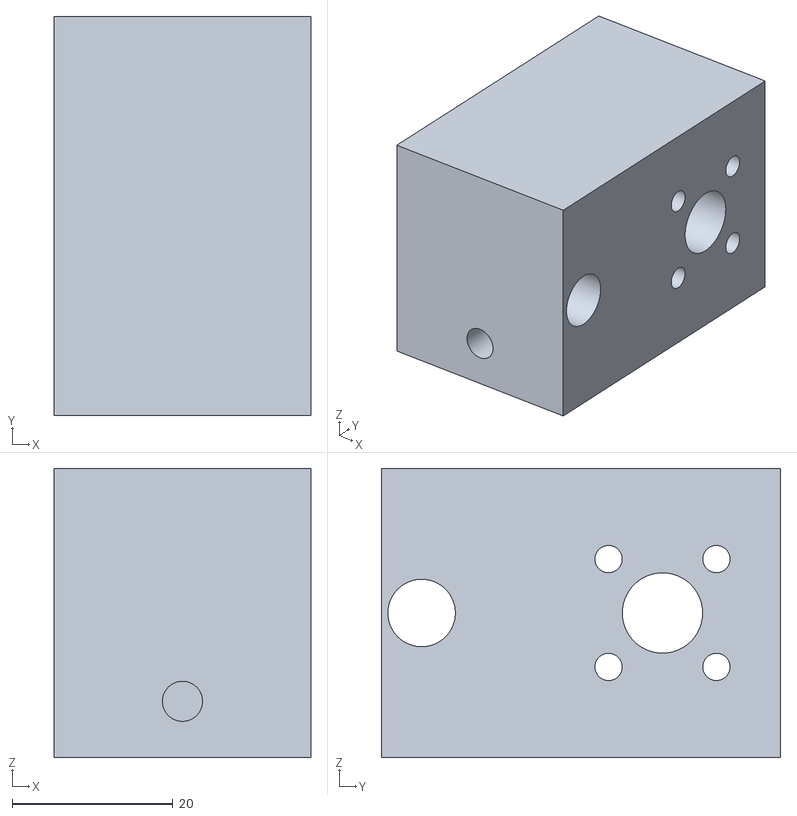
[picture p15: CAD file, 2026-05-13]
mechanical/stl/rig-carriage.stl
32.0 x 49.7 x 36.0

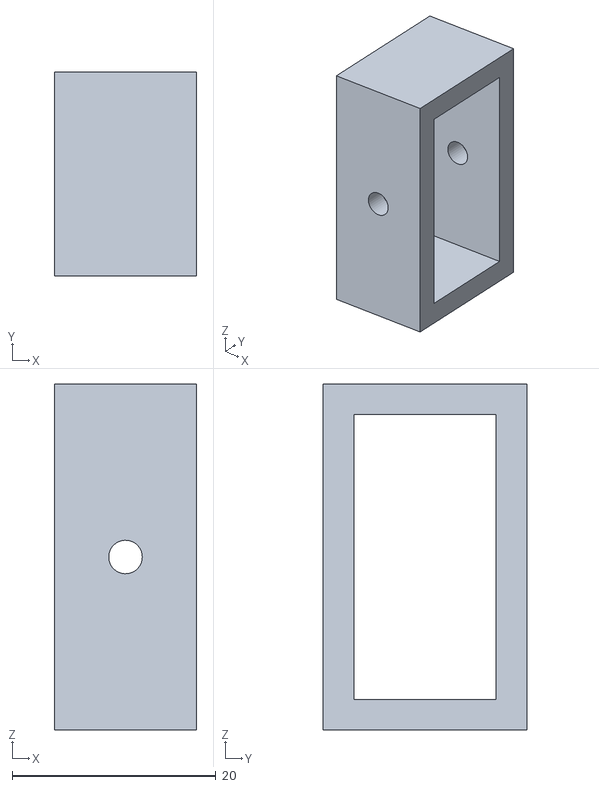
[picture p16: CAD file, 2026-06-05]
mechanical/v2/cad/sketches/option1-yoke.stl
14.0 x 20.0 x 34.0

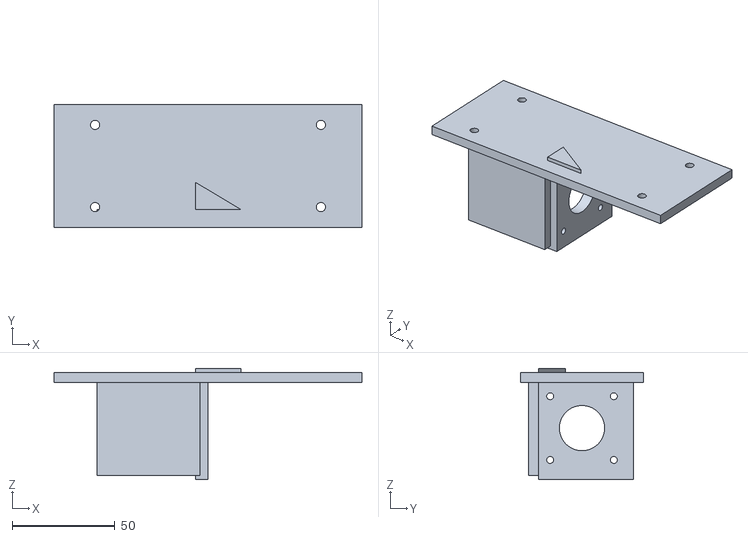
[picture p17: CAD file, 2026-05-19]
mechanical/v2/stl/sash-motor-mount.stl
150.0 x 60.0 x 54.3

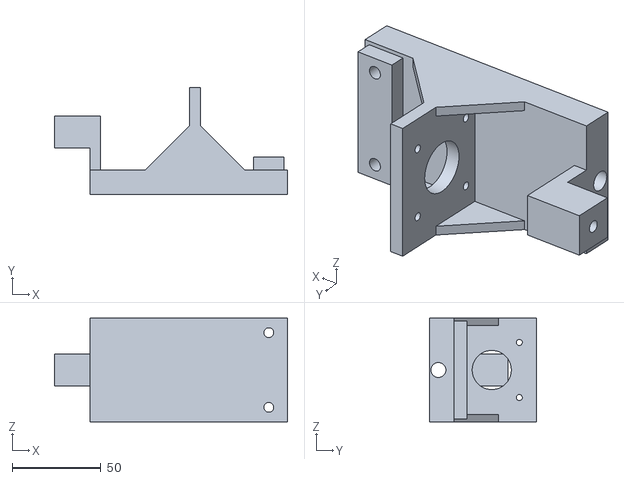
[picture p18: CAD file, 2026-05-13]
mechanical/stl/rig-motor-mount.stl
131.0 x 60.1 x 58.3

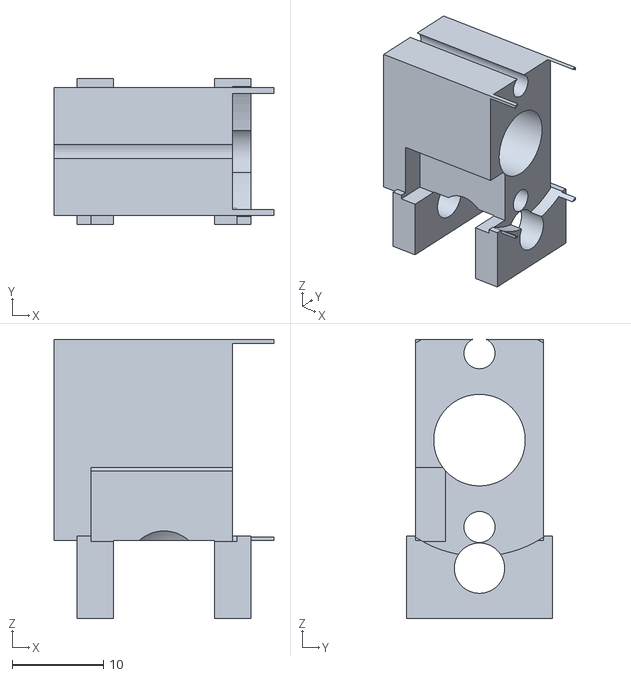
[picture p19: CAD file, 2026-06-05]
mechanical/v2/cad/sketches/option3-block.stl
24.0 x 16.0 x 30.5

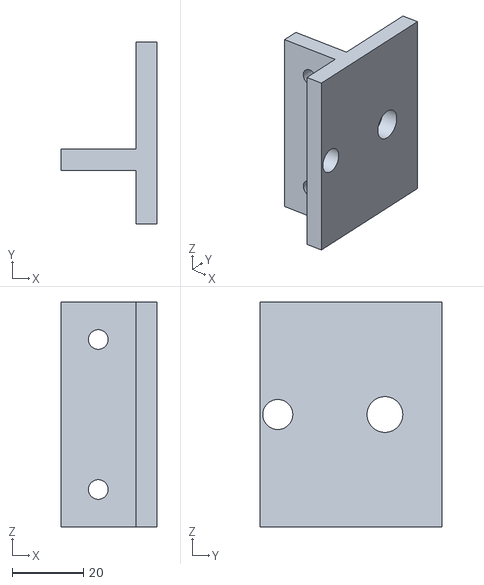
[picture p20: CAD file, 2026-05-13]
mechanical/stl/rig-far-bearing.stl
27.0 x 51.0 x 63.0

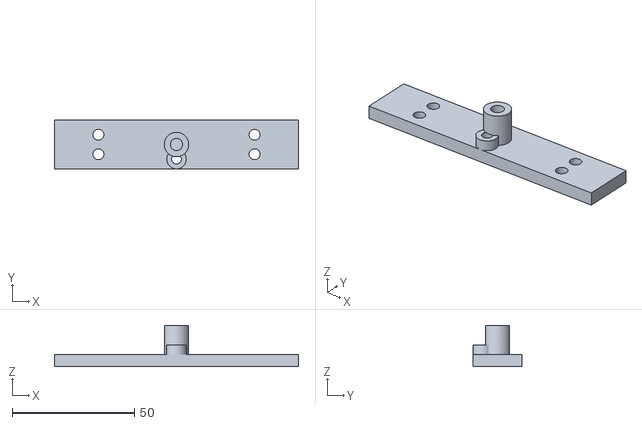
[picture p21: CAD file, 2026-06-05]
mechanical/v2/cad/sketches/option3-plate.stl
100.0 x 20.0 x 17.0

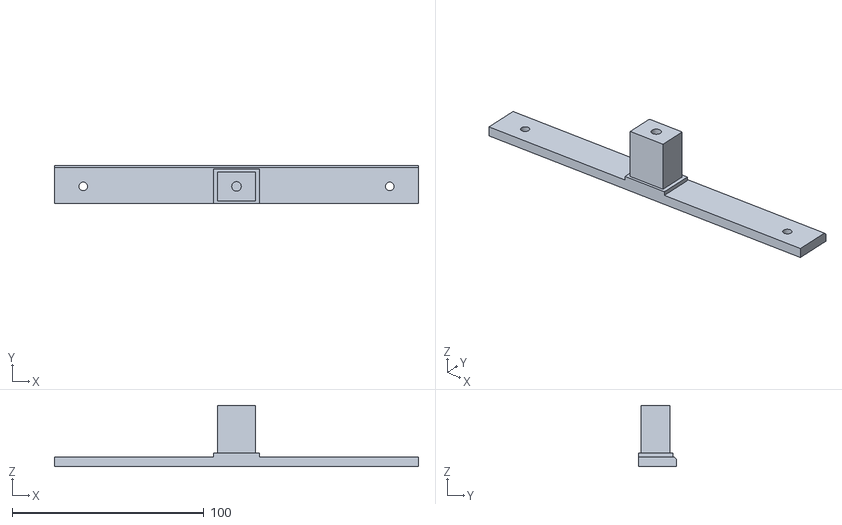
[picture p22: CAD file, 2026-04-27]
mechanical/stl/frame-bracket.stl
190.0 x 20.0 x 32.0

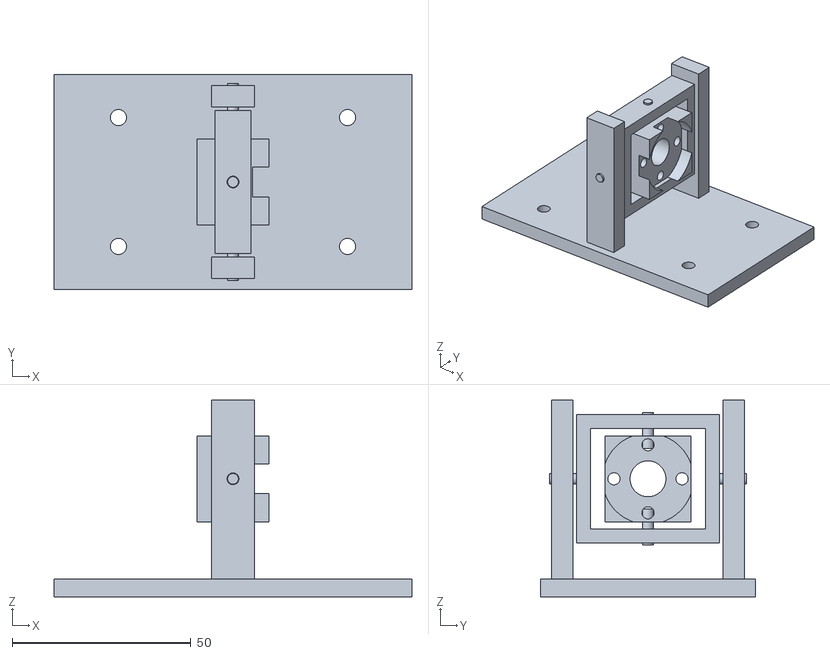
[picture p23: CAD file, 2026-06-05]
mechanical/v2/stl/frame-nut-gimbal.stl
100.0 x 60.0 x 55.0

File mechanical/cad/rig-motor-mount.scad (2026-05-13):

// Lead-screw rig — motor mount + KP08 #1 holder + frame-side rod-end.
//
// L-shaped bracket with a tab off the back. From -X to +X:
//   • Rod-end tab    — 18×18 horizontal stub with M6 tap, at SHAFT_Y.
//                      Carries the right-hand rod-end (CS10) that links
//                      the rig to the frame bracket on the window.
//   • Rear wall      — 6 mm column from the floor up to SHAFT_Y + 9,
//                      anchors the rod-end tab to the floor.
//   • Floor (under motor)
//                    — NEMA17_BODY_L + 2 mm of floor at Y = FLOOR_TOP_Y
//                      so the full motor body rests on the floor, not
//                      cantilevered. Motor's lower face touches floor.
//   • Back plate     — 6 mm vertical, carries the 4× M3 (31×31) holes
//                      and a 22 mm pilot bore for the motor flange.
//                      Extends down past the floor to enclose the
//                      anti-rotation rod hole at SHAFT_Y - 30.
//   • Coupler gap    — empty +X space for the Tr8 coupler.
//   • KP08 pedestal  — 7.15 mm pedestal lifting KP08 #1 up so its bore
//                      sits on the lead-screw axis.
//
// FLOOR_TOP_Y = -NEMA17_FACE/2 — the motor's bottom corners and the
// floor's top surface meet flush, and all 4 motor M3 holes sit above
// the floor (no access slots needed).
//
// Coordinate convention:
//   X axis: along the lead screw, +X = forward (toward the carriage / sash)
//   Y axis: vertical, +Y = up (Y=0 is the lead-screw axis)
//   Z axis: across the rig, +Z = away from the parallel anti-rotation rod
//
// Print orientation: back plate flat on the bed (the X- direction
// becomes the print +Z). Floor and pedestal will need a few support
// columns under their overhangs — slicer auto-supports work.
//
// Render:   openscad -o ../stl/rig-motor-mount.stl rig-motor-mount.scad

include <common.scad>;

// ---- design parameters (tune as needed) ----
PLATE_THK          = 6;         // back-plate thickness (X direction)
ANTI_ROT_OFFSET    = 30;        // anti-rotation rod offset below the lead-screw axis
ANTI_ROT_HOLE_D    = 8.4;       // 8 mm rod with print clearance
ANTI_ROT_HOLE_MARGIN = 5;       // material below the rod hole's lower edge
GUSSET_T           = 4;         // gusset rib thickness for L-corner stiffness
GUSSET_LEG         = 25;        // gusset leg length (square triangle)
COUPLER_MOTOR_GRIP = 12;        // mm of motor shaft buried inside the coupler
MOTOR_BACK_CLEAR   = 2;         // clearance between motor body and rear wall
REAR_WALL_THK      = 6;         // rear wall thickness along X
ROD_END_TAB_LEN    = 20;        // length of rod-end tab in -X (≥ ROD_END_TAP_D + 2 mm margin)
ROD_END_TAB_S      = 18;        // tab cross-section (square, Y and Z)
ROD_END_TAP_D      = 18;        // M6 tap depth for the rod-end shank

// ---- derived geometry ----
SHAFT_Y           = 0;                                  // lead-screw axis at Y=0
FLOOR_TOP_Y       = SHAFT_Y - NEMA17_FACE / 2;          // -21.15: motor body sits on floor
// Floor is ONE block: its bottom drops below the anti-rotation rod so
// the rod hole drills through floor material rather than air. The rod
// at Y = -30 with Ø8.4 hole has its lower edge at Y = -34.2; floor
// bottom at -ANTI_ROT_OFFSET - ANTI_ROT_HOLE_MARGIN gives 0.8 mm of
// material below the hole.
FLOOR_BOTTOM_Y    = SHAFT_Y - ANTI_ROT_OFFSET - ANTI_ROT_HOLE_MARGIN;  // -35
FLOOR_THK         = FLOOR_TOP_Y - FLOOR_BOTTOM_Y;       //  13.85
PEDESTAL_HEIGHT   = -KP08_BORE_HEIGHT - FLOOR_TOP_Y;    //  7.15: lifts KP08 base up to bore alignment
KP08_BASE_Y       = -KP08_BORE_HEIGHT;                  // -14: pedestal top = KP08 base bottom

// Back plate sits ABOVE the floor only. The old design had it extend
// down past the floor to enclose the anti-rotation rod hole; the floor
// now handles that, so the back plate stops where the floor starts.
BACK_PLATE_TOP_Y    = SHAFT_Y + NEMA17_FACE / 2 + 4;    //  25.15
BACK_PLATE_BOT_Y    = FLOOR_TOP_Y;                      // -21.15
BACK_PLATE_W        = NEMA17_FACE + 16;                 //  58.3: Z width with margin

// Floor extends behind the back plate far enough to seat the full motor
// body (NEMA17_BODY_L) plus a small clearance, plus the rear wall.
MOTOR_FLOOR_EXT   = NEMA17_BODY_L + MOTOR_BACK_CLEAR;   //  50

// Coupler clearance: KP08 must sit past the coupler. Coupler grips
// COUPLER_MOTOR_GRIP of the motor shaft, so its +X end sits at
// (shaft_tip - COUPLER_MOTOR_GRIP + COUPLER_L).
SHAFT_TIP_X       = NEMA17_SHAFT_L - PLATE_THK;         //  18
COUPLER_END_X     = SHAFT_TIP_X - COUPLER_MOTOR_GRIP + COUPLER_L;  // 31
KP08_START_X      = COUPLER_END_X + 1;                  //  32: 1 mm clearance past coupler
KP08_CENTER_X     = KP08_START_X + KP08_BASE_W / 2;     //  38.5
FLOOR_LEN_X       = KP08_START_X + KP08_BASE_W + 4;     //  49: small margin past KP08
PEDESTAL_X_W      = KP08_BASE_W + 4;                    //  17
PEDESTAL_Z_W      = KP08_BASE_L;                        //  55: matches KP08 base perpendicular to bore

// Rear wall (-X end of bracket) carries the frame-side rod-end tab.
REAR_WALL_X_INNER = -PLATE_THK - MOTOR_FLOOR_EXT;       // -56: rear wall's +X face (motor-side)
REAR_WALL_X_OUTER = REAR_WALL_X_INNER - REAR_WALL_THK;  // -62
REAR_WALL_TOP_Y   = SHAFT_Y + ROD_END_TAB_S / 2;        //   9: top of wall = top of tab

// ---- the part ----
module motor_mount() {
  difference() {
    union() {
      // Back plate. Motor faceplate bolts to the X- face; extends down
      // past the floor to enclose the anti-rotation rod hole.
      translate([-PLATE_THK, BACK_PLATE_BOT_Y, -BACK_PLATE_W / 2])
        cube([PLATE_THK, BACK_PLATE_TOP_Y - BACK_PLATE_BOT_Y, BACK_PLATE_W]);

      // Floor: ONE solid block from the rear wall's outer face all the
      // way forward past the KP08 pedestal, full BACK_PLATE_W in Z,
      // 13.85 mm tall in Y. Motor body rests on its top; anti-rotation
      // rod hole drills through the lower half.
      translate([REAR_WALL_X_OUTER, FLOOR_BOTTOM_Y, -BACK_PLATE_W / 2])
        cube([FLOOR_LEN_X - REAR_WALL_X_OUTER, FLOOR_THK, BACK_PLATE_W]);

      // KP08 pedestal — raises the KP08 base up to the lead-screw axis
      // alignment height (FLOOR_TOP_Y → KP08_BASE_Y).
      translate([KP08_CENTER_X - PEDESTAL_X_W / 2, FLOOR_TOP_Y, -PEDESTAL_Z_W / 2])
        cube([PEDESTAL_X_W, PEDESTAL_HEIGHT, PEDESTAL_Z_W]);

      // Rear-wall column — narrow vertical post that ties the rod-end
      // tab to the floor. Z width matches the tab.
      translate([REAR_WALL_X_OUTER, FLOOR_TOP_Y, -ROD_END_TAB_S / 2])
        cube([REAR_WALL_THK, REAR_WALL_TOP_Y - FLOOR_TOP_Y, ROD_END_TAB_S]);

      // Rod-end tab — extends in -X from the rear-wall column at the
      // lead-screw axis. M6 tap drilled inside it (see removals).
      translate([REAR_WALL_X_OUTER - ROD_END_TAB_LEN, SHAFT_Y - ROD_END_TAB_S / 2, -ROD_END_TAB_S / 2])
        cube([ROD_END_TAB_LEN, ROD_END_TAB_S, ROD_END_TAB_S]);

      // Gussets at the BACK PLATE L-corners, both +X (KP08 side) and
      // -X (motor side).
      for (z = [-BACK_PLATE_W / 2, BACK_PLATE_W / 2 - GUSSET_T]) {
        translate([0, FLOOR_TOP_Y, z])
          linear_extrude(GUSSET_T)
            polygon([[0, 0], [GUSSET_LEG, 0], [0, GUSSET_LEG]]);
        translate([-PLATE_THK, FLOOR_TOP_Y, z])
          linear_extrude(GUSSET_T)
            polygon([[0, 0], [-GUSSET_LEG, 0], [0, GUSSET_LEG]]);
      }
    }

    // ---- removals ----

    // Motor shaft clearance bore through back plate
    translate([-PLATE_THK - 1, SHAFT_Y, 0])
      rotate([0, 90, 0])
        cylinder(d = NEMA17_BORE_D, h = PLATE_THK + 2);

    // 4× M3 motor mount holes (31 × 31 pattern around the shaft)
    for (dy = [-NEMA17_HOLE_SPACING / 2, NEMA17_HOLE_SPACING / 2])
      for (dz = [-NEMA17_HOLE_SPACING / 2, NEMA17_HOLE_SPACING / 2])
        translate([-PLATE_THK - 1, SHAFT_Y + dy, dz])
          rotate([0, 90, 0])
            cylinder(d = NEMA17_HOLE_D, h = PLATE_THK + 2);

    // KP08 mounting holes — through floor + pedestal. Cylinder axis must
    // run vertically (along Y), otherwise OpenSCAD's default Z-axis
    // cylinder leaves a "scoop" instead of a through-hole.
    for (z = [-KP08_HOLE_SPACING / 2, KP08_HOLE_SPACING / 2])
      translate([KP08_CENTER_X, FLOOR_BOTTOM_Y - 1, z])
        rotate([-90, 0, 0])
          cylinder(d = KP08_HOLE_D, h = FLOOR_THK + PEDESTAL_HEIGHT + 2);

    // Anti-rotation rod hole — drilled through the rod sleeve + back
    // plate, the full bracket length. Cylinder spans from before the
    // sleeve's -X face to past its +X face so the hole opens cleanly
    // at both ends of the part.
    translate([REAR_WALL_X_OUTER - 1, SHAFT_Y - ANTI_ROT_OFFSET, 0])
      rotate([0, 90, 0])
        cylinder(d = ANTI_ROT_HOLE_D, h = FLOOR_LEN_X - REAR_WALL_X_OUTER + 2);
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

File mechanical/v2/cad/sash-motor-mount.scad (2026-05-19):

// v2 sash-side motor mount.
//
// L-bracket that bolts to the sash top rail (4× M4 self-tappers, VHB
// tape on the back) and carries the NEMA17 motor (4× M3 in the
// standard 31×31 pattern). The motor's shaft points along the rail,
// toward the frame anchor at the top-middle of the window. From the
// motor's faceplate, the shaft connects to a Ø5–Ø8 universal joint,
// then to the lead screw — both off-bracket.
//
// Coordinate convention (bracket local):
//   X axis: along the lead screw / sash top rail, +X = toward the frame anchor
//   Y axis: vertical (parallel to gravity when installed), +Y = up
//   Z axis: perpendicular to the sash face, +Z = into the room
//
// Origin: at the center of the motor mount wall's +X face (where the
// shaft exits). The motor body sits at X < 0, sash plate at X > 0.
//
// Print orientation: sash plate flat on the bed (Z = 0 side down).
// The motor mount wall rises in print +Z. Floor + gussets under the
// motor body need supports under their X-direction overhangs.
//
// Render:   openscad -o ../stl/sash-motor-mount.stl sash-motor-mount.scad

include <../../cad/common.scad>;

// ---- design parameters ----
PLATE_W           = 150;    // X length of sash mounting plate
PLATE_H           = 60;     // Y height of sash mounting plate
SASH_PLATE_THK    = 5;      // Z thickness of sash plate
WALL_THK          = 6;      // X thickness of motor mount wall
SCREW_INSET_X     = 20;     // M4 self-tapper inset from short edges
SCREW_INSET_Y     = 10;     // M4 self-tapper inset from long edges
GUSSET_T          = 4;      // gusset rib thickness
GUSSET_LEG        = 22;
MOTOR_FLOOR_EXT   = NEMA17_BODY_L + 2;  // floor under motor body in -X

// ---- derived geometry ----
SHAFT_Y           = 0;
FLOOR_TOP_Y       = SHAFT_Y - NEMA17_FACE / 2;       // -21.15: motor sits on floor
FLOOR_BOTTOM_Y    = FLOOR_TOP_Y - SASH_PLATE_THK;    // -26.15: matches plate Z thickness
SHAFT_Z           = -(NEMA17_FACE / 2 + 6);          // motor body in -Z, sash plate at Z=0

// Wall extends a bit above and below the motor face so the M3 holes
// have a few mm of material around them.
WALL_Y_TOP        = SHAFT_Y + NEMA17_FACE / 2 + 4;   // = 25.15
WALL_Y_BOT        = FLOOR_TOP_Y;                     // = -21.15 — joins motor floor
WALL_Z_OUTER      = SHAFT_Z - NEMA17_FACE / 2 - 4;   // -31.15: behind the motor body
WALL_Z_INNER      = 0;                               // toward the sash plate

// Sash plate sits AGAINST the sash room-side face. Plate occupies the
// X range covered by the bracket; the motor body extends in -X beyond
// the plate's -X edge.
SASH_PLATE_X_MIN  = -PLATE_W / 2;
SASH_PLATE_X_MAX  =  PLATE_W / 2;
SASH_PLATE_Z_MAX  = 0;
SASH_PLATE_Z_MIN  = -SASH_PLATE_THK;

// Motor faceplate sits at X = -WALL_THK (against the wall's -X face);
// motor body extends 48 mm further in -X. Shaft exits the wall at X = 0
// and continues another (NEMA17_SHAFT_L - WALL_THK) = 18 mm into open
// air, where the U-joint picks it up.
MOTOR_FACE_X      = -WALL_THK;
MOTOR_BACK_X      = MOTOR_FACE_X - NEMA17_BODY_L;
SHAFT_TIP_X       = MOTOR_FACE_X + NEMA17_SHAFT_L;   // 18

// Small "floor" under the motor body — supports its weight so the
// M3 mounting bolts don't carry the full cantilever moment. Floor
// sits between motor bottom and where the sash plate would be.
FLOOR_Z_MIN       = SHAFT_Z - NEMA17_FACE / 2 - 2;
FLOOR_Z_MAX       = SHAFT_Z + NEMA17_FACE / 2 + 2;
FLOOR_BOT_Y       = FLOOR_TOP_Y - SASH_PLATE_THK;

module sash_motor_mount() {
  difference() {
    union() {
      // Sash plate (against sash room-side face).
      translate([SASH_PLATE_X_MIN, -PLATE_H / 2, SASH_PLATE_Z_MIN])
        cube([PLATE_W, PLATE_H, SASH_PLATE_THK]);

      // Motor mount wall (perpendicular to the screw axis).
      translate([-WALL_THK, WALL_Y_BOT, WALL_Z_OUTER])
        cube([WALL_THK, WALL_Y_TOP - WALL_Y_BOT, WALL_Z_INNER - WALL_Z_OUTER]);

      // Floor under motor body — supports the cantilever weight.
      translate([MOTOR_BACK_X, FLOOR_BOT_Y, FLOOR_Z_MIN])
        cube([MOTOR_FLOOR_EXT, SASH_PLATE_THK, FLOOR_Z_MAX - FLOOR_Z_MIN]);

      // Connector ribs from the motor mount wall down to the sash plate
      // (one above, one below the motor body) so the wall doesn't just
      // cantilever off the plate at one edge.
      for (zsign = [-1, 1]) {
        translate([-WALL_THK,
                   FLOOR_TOP_Y,
                   zsign > 0 ? -GUSSET_T / 2 : -GUSSET_T / 2])
          linear_extrude(GUSSET_T)
            polygon([
              [0, 0],
              [0, -PLATE_H / 2 - FLOOR_TOP_Y + GUSSET_LEG],
              [GUSSET_LEG, 0]]);
      }
    }

    // ---- removals ----

    // M4 self-tapper holes through the sash plate, four corners.
    for (x = [SASH_PLATE_X_MIN + SCREW_INSET_X, SASH_PLATE_X_MAX - SCREW_INSET_X])
      for (y = [-PLATE_H / 2 + SCREW_INSET_Y, PLATE_H / 2 - SCREW_INSET_Y])
        translate([x, y, SASH_PLATE_Z_MIN - 0.1])
          cylinder(h = SASH_PLATE_THK + 0.2, d = M4_HOLE);

    // Motor shaft clearance bore through the wall.
    translate([-WALL_THK - 1, SHAFT_Y, SHAFT_Z])
      rotate([0, 90, 0])
        cylinder(d = NEMA17_BORE_D, h = WALL_THK + 2);

    // 4× M3 motor mount holes (31 × 31 pattern around the shaft).
    for (dy = [-NEMA17_HOLE_SPACING / 2, NEMA17_HOLE_SPACING / 2])
      for (dz = [-NEMA17_HOLE_SPACING / 2, NEMA17_HOLE_SPACING / 2])
        translate([-WALL_THK - 1, SHAFT_Y + dy, SHAFT_Z + dz])
          rotate([0, 90, 0])
            cylinder(d = NEMA17_HOLE_D, h = WALL_THK + 2);
  }
}

sash_motor_mount();

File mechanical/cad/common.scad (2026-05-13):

// Common parameters for the window-opener brackets.
//
// Units: millimetres. All parts share these values so changes propagate.
// Render with:
//   openscad -o sash-bracket.stl sash-bracket.scad
//   openscad -o frame-bracket.stl frame-bracket.scad

// -------- hole / clearance sizes --------
M4_HOLE      = 4.5;   // self-tapper clearance in PVC
M6_CLEAR     = 6.5;   // clearance for M6 rod-end shank
M6_TAP       = 5.0;   // tap drill for M6 (tap-to-size in post)

// -------- target window --------
// Reference only — used by consumers of these bracket CAD files.
WIN_WIDTH    = 845;
WIN_HEIGHT   = 1325;
D_FROM_HINGE = 120;   // moving-anchor offset from the hinge side

// -------- KP08 pillow-block bearing (per grema3d datasheet, 2026-05-13) --------
// Datasheet variable names (KP08 column, shaft d = 8 mm):
//   L  = 55  total base width PERPENDICULAR to bore
//   A  = 13  body width ALONG bore (the bearing axis)
//   J  = 42  bolt-hole spacing (c-to-c)
//   N  = 5   bolt-hole diameter (M5)
//   H  = 14  base bottom → bore centre  (CRITICAL — was 17 in earlier guess)
//   H1 = 5   base thickness
//   H2 = 28  total height
//
// SCAD variable names retained for backwards-compat with rig-*.scad files,
// but their MEANINGS are now spec-driven, not measured-guess:
//   KP08_BASE_L      → L  (along Y, perpendicular to lead screw)
//   KP08_BASE_W      → A  (along X, along lead screw)
//   KP08_HOLE_SPACING → J
//   KP08_HOLE_D       → N (M5 clearance)
//   KP08_BORE_HEIGHT  → H
//   KP08_BODY_W       → body width along Y (perpendicular to bore)
//   KP08_TOTAL_H      → H2
KP08_BASE_L       = 55;       // L — base width perpendicular to bore
KP08_BASE_W       = 13;       // A — width ALONG bore axis (NB: lead screw direction)
KP08_HOLE_SPACING = 42;       // J — bolt-hole c-to-c
KP08_HOLE_D       = 5.5;      // M5 clearance (N = 5 mm bolt, + a hair)
KP08_HOLE_SLOT_L  = 8;        // slot length (legacy; some KP08s have slotted holes)
KP08_BORE_HEIGHT  = 14;       // H — base bottom to bore centre
KP08_BODY_W       = 30;       // approximate body width perpendicular to bore
KP08_TOTAL_H      = 28;       // H2 — total height

// -------- Prusa MK3 brass nut (per piese3d datasheet, 2026-05-13) --------
// Datasheet (Tr8x8 brass nut for MK3):
//   Flange OD      = 25       (was incorrectly measured as 19 — 19 is the
//                              bolt-hole *circle* diameter, not the flange OD)
//   Flange thk     = 4
//   Body OD        = 10
//   Body length    = 10
//   Total length   = 14       (= flange thk + body length)
//   Bolt circle    = Ø19      with 4 holes at 90°: 2× M3 threaded
//                              (vertically opposed) + 2× Ø4.1 clearance
//                              (horizontally opposed)
PRUSA_NUT_FLANGE_D       = 25;     // outer flange OD
PRUSA_NUT_FLANGE_THK     = 4;
PRUSA_NUT_BODY_D         = 10;
PRUSA_NUT_BODY_L         = 10;
PRUSA_NUT_TOTAL_L        = PRUSA_NUT_FLANGE_THK + PRUSA_NUT_BODY_L; // 14
PRUSA_NUT_BOLT_CIRCLE_D  = 19;     // diameter on which the 4 holes sit
PRUSA_NUT_M3_HOLE_D      = 3.4;    // M3 clearance (for the carriage side)
PRUSA_NUT_CLEAR_HOLE_D   = 4.1;    // the 2× Ø4.1 holes in the nut flange

// Legacy alias retained so existing rig-carriage.scad keeps compiling.
// Square-pattern spacing equivalent to the 19 mm bolt circle (diagonal 19,
// side = 19/√2 ≈ 13.43). Update rig-carriage.scad to use BOLT_CIRCLE_D for
// the correct alternating-hole pattern; this approximation gets close.
PRUSA_NUT_M3_SPACING     = 13.43;

// -------- LDO 42STH48-1684MAC NEMA17 (per LDO datasheet, 2026-05-13) --------
// Per the official LDO drawing (kb-3d datasheet):
//   Face            42.3 × 42.3 MAX
//   Body length     48 MAX
//   Mounting holes  4× M3 on 31 × 31 mm pattern, depth 4.5 min
//   Pilot boss      Ø22 (-0/-0.052)            ← was 22.5 in earlier guess
//   Shaft           Ø5 -0.002/-0.012, 24 ± 0.5 long
//   Shaft has a 15 mm flat (D-cut), 4.5 mm deep — not modelled here
NEMA17_FACE         = 42.3;
NEMA17_BODY_L       = 48;
NEMA17_HOLE_SPACING = 31;
NEMA17_HOLE_D       = 3.4;     // M3 clearance
NEMA17_HOLE_DEPTH   = 4.5;     // minimum tap depth into the motor face
NEMA17_BORE_D       = 22;      // pilot-boss OD (fits matching counterbore)
NEMA17_SHAFT_D      = 5;
NEMA17_SHAFT_L      = 24;
NEMA17_SHAFT_FLAT_L = 15;      // D-cut flat length, for coupler grip
NEMA17_SHAFT_FLAT_D = 4.5;     // D-cut depth from full Ø

// -------- Coupler --------
COUPLER_OD = 19;
COUPLER_L  = 25;

// -------- Lead screw --------
LEAD_SCREW_D    = 8;       // Tr8x8 outer diameter
LEAD_SCREW_LEAD = 8;       // 8 mm linear travel per revolution

// -------- bracket common --------
BRACKET_WIDTH  = 190;  // along the top rail (X axis in both parts)
PLATE_THK      = 5;    // plate wall thickness
PRINT_CLR      = 0.2;  // generic printer tolerance

// Render resolution — fine enough for holes, cheap enough for iteration.
$fa = 4;
$fs = 0.3;

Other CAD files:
mechanical/cad/frame-bracket.scad
mechanical/cad/rig-assembled.scad
mechanical/cad/rig-carriage.scad
mechanical/cad/rig-far-bearing.scad
mechanical/cad/sash-bracket.scad
mechanical/v2/cad/frame-nut-gimbal.scad
mechanical/v2/cad/sketches/option1-zpivot.scad
mechanical/v2/cad/sketches/option3-rodend.scad
mechanical/v2/cad/v2-assembled.scad

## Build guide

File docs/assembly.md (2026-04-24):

# Assembly

Photo-led build guide. Not written yet — gets filled in during Phase 2 of `PLAN.md`, after the brackets are printed and the first physical install is done.

Sections planned:

1. **Bench-test first.** Wire the ESP32 + driver + actuator on the bench per `hardware/wiring/<variant>.md`. Flash firmware. Verify open/close from HA before touching the window.
2. **Measure the window.** Width, height, sash weight; confirm the chosen actuator stroke covers turn mode (usually the longer arc).
3. **Dry-fit.** Place the printed brackets on the frame/sash with painter's tape. Cycle the window manually in tilt and turn modes to confirm no interference.
4. **Attach brackets.** VHB tape first, screws later (PVC window frames don't forgive mistakes).
5. **Install actuator.** Rod ends at both ends. Confirm no binding at any point in the stroke, in both modes.
6. **Route cables.** 12V + ESP32 USB-power (if keeping USB for serial) along the hinge side where flex is minimal.
7. **Calibrate.** Follow `calibration.md`.
8. **Mount enclosure.** ESP32 + driver + buck go in the enclosure on the frame near the actuator.

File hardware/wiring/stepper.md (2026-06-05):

# Wiring — Stepper variant

NEMA17 stepper driven by a BIGTREETECH TMC2209 V1.3 driver, controlled by a Seeed Studio XIAO ESP32-C6. STEP/DIR variant uses the bottom 6 lines; UART variant adds D6/D7 (and optionally D9 for stall detection).

## Pin map (XIAO ESP32-C6 → BTT TMC2209 V1.3)

| XIAO label | GPIO | Driver pad | Used by | Notes |
|---|---|---|---|---|
| D1 | GPIO1 | `DIR` | both variants | |
| D2 | GPIO2 | `STEP` | both variants | |
| D3 | GPIO21 | `EN` | both variants | Active-low. **Do not** set `inverted: true` in the UART variant — the slimcdk component inverts internally. |
| D6 | GPIO16 | `TX` | UART variant only | **1 kΩ in series** with this line. R10 on the driver bottom must be bridged first (factory NC). |
| D7 | GPIO17 | `RX` | UART variant only | Direct, no resistor. |
| D8 | GPIO19 | endstop switch (COM) | both variants | NO contact of switch → `GND`. Firmware uses `INPUT_PULLUP` + `inverted: true`. |
| D9 | GPIO20 | `DIAG` | UART variant, **optional** | **Not currently wired.** Adding this single wire enables interrupt-based stall detection in the slimcdk component (otherwise stall events are unreliable). Set `diag_pin: GPIO20` in `firmware/variants/stepper-uart.yaml` once wired. |
| 3V3 | — | `VIO` | both variants | Logic supply. |
| GND | — | `GND` | both variants | Logic ground (common with 12 V PSU GND). |
| 5V | — | (Buck `OUT+`) | both variants | Powered by MP1584 buck converter, not the driver. |

### V1.3 UART quirk — R10 must be bridged

The TMC2209 chip has a single bidirectional UART pin (`PDN_UART`). On the BTT V1.3 the `RX` and `TX` header pads are connected via **R10**, but **R10 ships unpopulated** (factory default). With R10 open:

- The `RX` pad is wired to `PDN_UART` directly — this is the only live UART pad out of the box.
- The `TX` pad is **not connected to anything** — wiring to it does nothing.

This is why a multimeter shows no continuity between RX and TX on a stock V1.3. The official BTT manual ([`BIGTREETECH-Stepper-Motor-Driver/TMC2209/V1.3/manual`](https://github.com/bigtreetech/BIGTREETECH-Stepper-Motor-Driver/tree/master/TMC2209/V1.3/manual)) says:

> *"To alter UART pin assignments for compatibility with different boards, solder the two pads at R10 together."*

So before flashing the UART variant: flip the driver over, find the **R10** pads on the bottom side (between the RX/TX header pins), and bridge them. After bridging, both `RX` and `TX` header pins go to the same `PDN_UART` net and the cross-wiring above (XIAO D6 → driver `RX`, XIAO D7 → driver `TX`) works as drawn.

**You also need a 1 kΩ resistor in series with the XIAO TX line.** The slimcdk ESPHome component README explicitly requires it:

> *"This is the ESPHome device's transmit pin. This should be connected through a 1 kΩ resistor to PDN_UART on the TMC2209."*

The 1 kΩ provides contention protection — when the chip is responding, it actively drives the line at the same time the XIAO TX is idling HIGH; without the resistor, the two outputs fight directly. Two equally good ways to add it:

1. **Solder a 1 kΩ SMD (0603/0805) into the R10 footprint** instead of a solder blob. This bridges R10 *through* the resistor — driver TX pad → 1 kΩ → PDN_UART, while RX pad stays direct. Cleanest option.
2. **Inline 1 kΩ on the wire** between XIAO D6 and the driver's TX pad. Solder-blob R10 closed, then put the 1 kΩ on the cable side.

Either way, XIAO D7 → driver RX stays direct (no resistor on the receive side).

**Alternative — single-wire UART** (no soldering on the driver): tie both XIAO `D6` (TX, with the 1 kΩ inline) and `D7` (RX, direct) to the driver's `RX` pad only. In the YAML, set `tx_pin` and `rx_pin` to the same GPIO. Same electrical behavior as option 2 above.

The XIAO ESP32-C6 only breaks out 11 GPIOs (D0-D10), so most ESP32-C6 examples that use GPIO 4-7 won't apply directly. **Avoid D0 (GPIO0) for the endstop** — it's a strapping pin and a low at boot causes the chip to enter download mode. D1-D3 + D8 give clean breakouts on opposite sides of the small board.

## Power

| From | To | Notes |
|---|---|---|
| 12V PSU `+` | Via 3A fuse → TMC2209 `VM` | Motor supply |
| 12V PSU `−` | TMC2209 `GND` | Common ground with ESP32 |
| 12V PSU `+` | Buck converter IN+ | Same 12V rail |
| Buck OUT 5V | ESP32 `5V` | ESP32 power |
| TMC2209 coil A1/A2 | Motor A-phase pair | Check datasheet for coil pairings |
| TMC2209 coil B1/B2 | Motor B-phase pair | |

**Required:** a 100 µF electrolytic capacitor across `VM` and `GND`, close to the TMC2209. Missing this cap is the #1 cause of driver death.

## Endstop / closed detection

**Current state (`stepper-uart.yaml`): the D8 micro-switch is NOT installed.**
Closed detection runs off the window's **own contact sensor, imported from Home
Assistant** (the built-in `homeassistant` platform — *not* an `external_component`).
Set the entity in the `closed_sensor_entity` substitution **in
`firmware/window-opener.yaml`** (default `binary_sensor.window_contact`; the entry
file overrides the variant's fallback). The HA contact is the homing reference
and the free-wheel move-detector. Convention assumed: HA state `on` = open,
`off` = closed — flip the `!...state` in `window_closed`'s lambda if reversed.

> Trade-off: homing now depends on the HA connection. If HA is unreachable at
> boot, the homing sweep can't confirm closed and position stays `unknown` until
> it reconnects (or the open-side StallGuard hard stop is hit).

To add a **physical** closed endstop later (makes homing local + HA-independent):

- Normally-open micro-switch (or magnetic reed + magnet on the carriage).
- One lead to XIAO `D8` (GPIO19), other lead to `GND`.
- Firmware uses `INPUT_PULLUP` with `inverted: true`.
- Uncomment the `endstop_closed` `binary_sensor` block in `stepper-uart.yaml`
  **and** the `|| id(endstop_closed).state` term in `window_closed`'s lambda.

## Current limit

- **STEP/DIR variant (`variants/stepper.yaml`):** set the trimpot on the BTT V1.3 so Vref ≈ 1.0 V (for the LDO 42STH48-1684MAC motor at ~70 % of its 1.68 A rating). Vref formula: `I_RMS = Vref × (1/√2) / (R_SENSE × 2.5)`.
- **UART variant (`variants/stepper-uart.yaml`):** Vref is **ignored**. The component sets `run_current: 1100mA` (motion) and `hold_current: 500mA` (standstill) via UART register writes; the chip's `I_SCALE_ANALOG` is left at 0 so the VREF pin is disconnected from the current scaler. Turning the pot has no effect.

## Direction sanity check

1. Home the carriage against the endstop.
2. Send **open** → carriage should move **away** from the endstop.
3. Send **close** → carriage should move **toward** the endstop.

If reversed, swap one coil pair (e.g. A1 ↔ A2) at the driver.

## Schematic

```
     +12V PSU+ ──┬── 3A fuse ──┬── TMC2209 VM ──┬── 100–470µF ─┐
                 │             │                │              │
                 │             └── Buck IN+     │              │
                 │                 Buck OUT+ ── XIAO 5V        │
                 │                 Buck OUT− ─┬ XIAO GND       │
     +12V PSU− ──┴─────────────── TMC2209 GND┤                 │
                                              └──── common GND

    XIAO D1  (GPIO1)  ──────────── TMC2209 DIR        TMC2209 A1/A2 ── motor coil A
    XIAO D2  (GPIO2)  ──────────── TMC2209 STEP       TMC2209 B1/B2 ── motor coil B
    XIAO D3  (GPIO21) ──────────── TMC2209 EN
    XIAO D6  (GPIO16) ──[1 kΩ]──── TMC2209 TX  ┐
    XIAO D7  (GPIO17) ──────────── TMC2209 RX  ┘ (UART; both pads → PDN_UART once R10 is bridged)
    XIAO D8  (GPIO19) ──────────── endstop COM ── (NO) ── GND
    XIAO D9  (GPIO20) ┄┄┄┄┄┄┄┄┄┄┄┄ TMC2209 DIAG  (optional, not yet wired; enables stall detection)
    XIAO 3V3          ──────────── TMC2209 VIO
```

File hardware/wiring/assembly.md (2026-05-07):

# Wiring assembly — soldering order

This page tells you in what order to put the perfboard together so you don't paint yourself into a corner. Use the schematic at [`../schematic.svg`](../schematic.svg) as the source of truth for which pin connects where, and [`../perfboard-layout.svg`](../perfboard-layout.svg) for physical placement.

## Bill of materials

| Qty | Part | Notes |
|---:|---|---|
| 1 | Perfboard, 70 × 90 mm, 2.54 mm grid | Generic, available at any electronics shop. |
| 1 | Seeed Studio XIAO ESP32-C6 | Castellated edges — solder direct or use 2× 1×7 female headers (recommended). |
| 1 | TMC2209 V1.3 (with heatsink) | Goes on female pin headers, removable. |
| 1 | DC-DC buck module (MP1584 mini *or* LM2596) | The MP1584-style mini board takes ~14 × 22 mm; LM2596 is bigger but works the same. Soldered direct (mini board) or on female headers (LM2596). |
| 1 | 470 µF / 35 V electrolytic cap | Mind polarity. |
| 1 | Inline 5 A blade fuse holder + fuse | Or panel-mount fuse holder. |
| 2 | 2-pin screw terminal (5.08 mm pitch) | 12 V input + endstop. |
| 1 | 4-pin screw terminal | Motor output. |
| ~30 cm | Solid 22 AWG wire (multiple colours) | For jumpers between modules. |
| 4 | M3 × 6 mm screws + nylon spacers | To mount the perfboard in an enclosure later. |

## Tools

- Soldering iron (350 °C for lead-free, 320 °C for leaded)
- Solder (0.6 – 0.8 mm)
- Solder wick or sucker (for mistakes)
- Multimeter (for continuity + Vref tuning)
- Wire stripper, side cutters
- Helping hands or a board holder

## Wire gauges & lengths

| Wire role | Carries | Recommended cross-section | Notes |
|---|---|---|---|
| 12 V from PSU to board | up to ~3 A | **0.75 mm²** silicone | 0.5 mm² acceptable for runs < 30 cm |
| 12 V on-board (after fuse → TMC2209 VM, buck VIN) | up to 3 A | **0.75 mm²** | thick solder bridges OK in lieu of jumper wire |
| GND bus | matches 12 V | **0.75 mm²** | star-ground to one node |
| TMC2209 → motor coils | 1.7 A peak, chopped at ~30 kHz | **0.5 – 0.75 mm²** silicone, **twist each coil pair** (~5 twists per 10 cm) | reduces RFI |
| XIAO logic, TMC2209 STEP / DIR / EN | ~1 mA | **0.14 mm²** Dupont jumper or ribbon | gauge doesn't matter; pick for flexibility |
| Endstop (XIAO ↔ switch) | ~1 mA | **0.14 mm²** | use a 2-pin JST-XH on the switch end for easy swap |

**Wire lengths:**

- Endstop: **30–60 cm** typical for the real install (perfboard at the motor end of the rig, switch ~3–5 cm from the carriage's closed position). Any length up to ~1.5 m is fine electrically — the internal pull-up doesn't care.
- 12 V from PSU to perfboard: cut to fit; keep short and tidy (1–2 m max).
- Motor: the LDO ships with a ~1 m pigtail; trim or extend as needed. If extending, splice with solder + heatshrink and re-twist the pairs.
- Logic and on-board jumpers: 5–10 cm each, routed flat against the perfboard back.

## Soldering order

The rule: **solder the lowest-profile parts first**, then progressively taller. Otherwise the board won't sit flat against your work surface for soldering taller parts.

### 1. Female pin headers for XIAO ESP32-C6 and TMC2209

These are the lowest profile after the bare board. Use **female** headers so the modules plug in/out — saves you from soldering a small module permanently and discovering it's a dud.

- XIAO ESP32-C6: two rows of 1×7 — the XIAO has 7 pads on each long edge. (You can also direct-SMD-solder the XIAO via its castellated edges if you'd rather not use headers, but headers make life easier.)
- TMC2209: two rows of 1×8.

Solder one corner pin first, flip the board, check the header is flush and square against the board, then solder the rest. **Don't solder all pins at once on one side** — heat warps the plastic.

### 2. Power-side jumpers (red and black)

Lay down the +12 V and GND buses now while the board is still mostly flat. Use **solid 22 AWG** so you can route along the back side of the board cleanly.

- Red wire from the 12 V input terminal → through the fuse → to a node where the buck (MP1584/LM2596) IN+ and the TMC2209 VM both tap in.
- Black wire (GND) bus from the input terminal across the bottom edge of the board, with stubs going up to: buck (MP1584/LM2596) IN−, buck (MP1584/LM2596) OUT−, TMC2209 GND (×2), ESP32 GND (×2), 470 µF cap minus, endstop NO.

**Star ground**: every GND wire converges on one point. Don't daisy-chain — stub from the bus.

### 3. The 470 µF capacitor

Solder it directly across the TMC2209's VM and GND pins, leads as short as possible — under 2 cm.

> Polarity check before soldering: the **white stripe on the cap = negative lead**. Solder negative to GND, positive to +12 V (VM).

### 4. Logic-side jumpers (yellow / signal wires)

Connect from the XIAO ESP32-C6's GPIOs to the TMC2209's logic pins:

| XIAO label | GPIO | TMC2209 |
|---|---|---|
| D1 | GPIO1 | DIR |
| D2 | GPIO2 | STEP |
| D3 | GPIO21 | EN |
| 3V3 | — | VIO |
| GND | — | GND |

And the endstop:

| XIAO label | GPIO | Endstop |
|---|---|---|
| D8 | GPIO19 | COM |
| GND | — | NO |

These are low-current — any 22-26 AWG wire is fine.

### 5. The 5 V jumper from buck (MP1584/LM2596) to XIAO

Orange wire, one stub: buck (MP1584/LM2596) OUT+ → XIAO 5V pin (top-left of the board, opposite the USB-C connector). buck (MP1584/LM2596) OUT− is already on the GND bus.

> **Set the buck output to 5 V before this connection.** With nothing on OUT, hook a multimeter between OUT+ and OUT−, power up the 12 V side, and verify the reading. If the module is *adjustable* (small SMD pot on the MP1584-style mini board, or the brass screw pot on the LM2596), turn it until you read 5.00 V. Some MP1584 boards are *fixed* at 5 V — in that case just confirm and move on. Power down, then make the connection.

### 6. Screw terminals

Power input (2-pin), motor output (4-pin), endstop (2-pin) — soldered last because they're tall and stick up off the board.

## First power-up

Bench PSU at 12.0 V, current limit 1 A.

1. Plug the XIAO ESP32-C6 into its female headers.
2. Plug TMC2209 into its female headers (no motor connected yet).
3. Power up. Multimeter on the buck (MP1584/LM2596) OUT+ → should read 5.0 V.
4. Touch the multimeter to the TMC2209's VREF test point and tweak its pot to **1.0 V**. (Skip if you already did this in `bench-test.md`.)
5. Power down. Connect the motor wires to the screw terminal — pair the wires by coil (multimeter continuity test if unsure).
6. Connect the endstop.
7. Power up again. Watch the bench PSU's current readout — should sit around 100-300 mA at idle.
8. Flash firmware (`esphome run firmware/window-opener.yaml`) over USB.
9. Run the four success-criteria tests from [`docs/bench-test.md`](../../docs/bench-test.md).

If anything weird happens, **kill power first** before debugging. The bench PSU's current limit is your safety net.

## Going to a fabricated PCB later

If you decide later you want a proper PCB instead of perfboard:

1. The schematic in `hardware/schematic.svg` is the source of truth — it translates directly to KiCad.
2. JLCPCB will fab 5× of a 100 × 80 mm 2-layer PCB for ~$5 + ~$10 shipping. Total: $15 for a stack of cleaner-looking boards.
3. KiCad project skeleton is **not yet committed** to the repo — open question, see `PLAN.md`.

The perfboard build above is plenty for v1; PCB fab is a polish step.

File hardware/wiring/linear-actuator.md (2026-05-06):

# Wiring — Linear Actuator variant

12V DC linear actuator driven by a BTS7960 H-bridge, controlled by an ESP32.

## Pin map (Seeed Studio XIAO ESP32-C6)

| XIAO label | GPIO | Goes to | Notes |
|---|---|---|---|
| D1 | GPIO1 | BTS7960 `RPWM` | Forward PWM (extend) |
| D2 | GPIO2 | BTS7960 `LPWM` | Reverse PWM (retract) |
| 3V3 | — | BTS7960 `R_EN` + `L_EN` | Tie both enables high |
| GND | — | BTS7960 `GND` | Common ground |
| (optional) D0 / A0 | GPIO0 | 10-turn pot wiper | ADC1_CH0 |
| (optional) 3V3 / GND | — | Pot ends | Orient so extend = higher voltage |

The XIAO ESP32-C6 has 11 broken-out GPIOs. Pins above use only D0/D1/D2 — leaves D3-D10 free for future expansion (status LED, additional sensors, etc.).

## Power

| From | To | Notes |
|---|---|---|
| 12V PSU `+` | BTS7960 `B+` via inline 5A fuse | Fuse near the PSU, not at the driver |
| 12V PSU `−` | BTS7960 `B−` | Common ground with ESP32 |
| 12V PSU `+` | Buck converter IN+ | Same 12V rail |
| Buck OUT+ / OUT− (5V) | ESP32 `5V` / `GND` | Feed ESP32 via its 5V pin, not 3V3 |
| BTS7960 `M+` / `M−` | Actuator motor leads | Polarity determines extend direction |

Add a **TVS diode** (1.5KE18CA) across the actuator motor leads to snub inductive spikes.

## Direction sanity check

After first flash:

1. Send **open** → actuator should **extend** (push sash away from frame anchor).
2. Send **close** → actuator should **retract**.

If reversed, swap `M+` / `M−` at the driver (easier than editing firmware).

## Schematic

```
     +12V PSU+ ──┬── 5A fuse ──┬── BTS7960 B+ ──┐
                 │             │                │
                 │             └── Buck IN+     │
                 │                 Buck OUT+ ── ESP32 5V
                 │                 Buck OUT− ─┬ ESP32 GND
     +12V PSU− ──┴─────────────── BTS7960 B−─┤
                                              └─ common GND

    XIAO D1 (GPIO1) ── BTS7960 RPWM           BTS7960 M+ ── Actuator +
    XIAO D2 (GPIO2) ── BTS7960 LPWM           BTS7960 M− ── Actuator −
    XIAO 3V3        ─┬─ BTS7960 R_EN                    (TVS 1.5KE18CA across M+/M−)
                     └─ BTS7960 L_EN
```

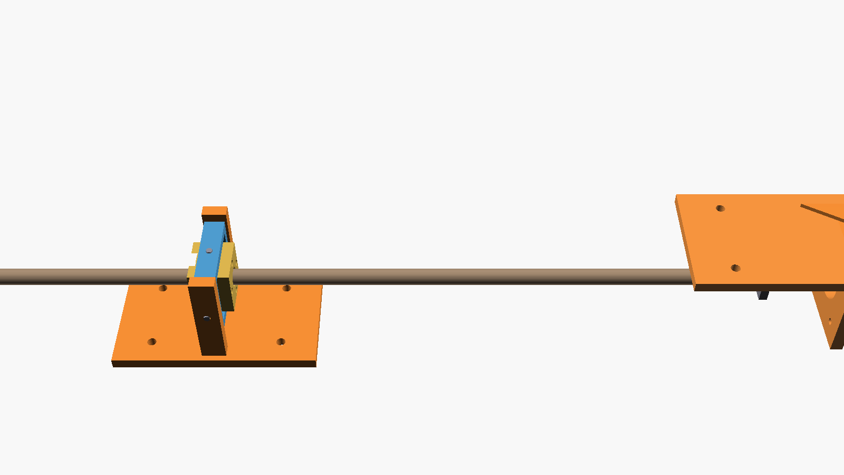
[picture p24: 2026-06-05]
mechanical/v2/stl/v2-assembled-iso.png

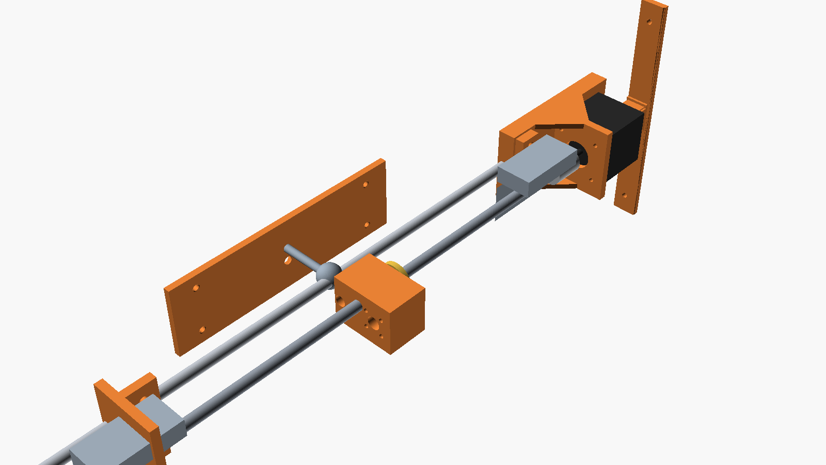
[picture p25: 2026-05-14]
mechanical/stl/rig-assembled-iso.png

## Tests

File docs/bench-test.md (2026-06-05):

# Bench test — Phase 1

The goal of this phase is **proving the electronics drive the motor before touching the window**. If anything is going to be wrong (mis-flashed firmware, wrong pin map, dead driver, miswired coils), it's much cheaper to find out at the desk than after you've stuck a bracket to a window with VHB.

## Success criteria

By the end of this phase, all of the following work:

1. Home Assistant auto-discovers `cover.window_opener` after the ESP32-C6 is flashed.
2. `cover.open_cover` from HA → motor spins one way.
3. `cover.close_cover` from HA → motor spins the other way.
4. `cover.set_cover_position 50` → motor moves a calibrated amount and stops.
5. Touching the endstop switch resets reported position to 0 in HA.

No window. No brackets. No lead screw yet. **Just a bare motor on the desk** moving on command.

## Parts you need on the bench

- Seeed Studio XIAO ESP32-C6 + USB-C cable
- TMC2209 V1.3 (with stick-on heatsink)
- LDO 42STH48-1684MAC stepper motor
- **≥ 100 µF / ≥ 25 V electrolytic capacitor** — non-negotiable, see "Why the cap" below. 470 µF / 35 V is a fine upgrade.
- 12 V supply: a configurable bench PSU (set 12.0 V, current limit 1 A for first power-on, raise to 3 A once moving cleanly) or a fixed 12 V / 5 A AC-DC brick.
- XIAO power: USB during bench testing — no need for the buck (MP1584 / LM2596) yet.
- Creality endstop microswitch (optional for steps 1-4, required for step 5)
- 8-10 jumper wires (Dupont female-to-female / female-to-male)
- A breadboard or just twisted/soldered wire splices
- Multimeter (for setting Vref)

> **Why the cap:** stepper coils are inductors. Every microstep, the TMC2209 switches coil current off; the inductor's stored energy creates a voltage spike on `VM`. Without a local cap to absorb those spikes, they exceed the IC's 28 V rating and silicon-erode the FETs until one shorts. ≥100 µF / ≥25 V electrolytic, mounted *within a few cm of the chip's VM/GND pins*, polarity-correct (white stripe to GND). The cap at the PSU end of the wires is *not* a substitute — wire inductance is what makes the cap-at-the-driver mandatory.

## Wiring — do this with everything powered off

### 1. The cap goes first

Solder a **100 µF / ≥ 25 V electrolytic** directly across the TMC2209's `VM` and `GND` pins on the underside of the module, with the leads as short as you can manage. Mind the polarity — the white stripe is the negative side, goes to GND. *Do not skip this step. Do not power up without it.*

### 2. Logic side: XIAO ESP32-C6 → TMC2209

| XIAO label | GPIO | → | TMC2209 pin |
|---|---|:-:|---|
| D2 | GPIO2 | → | STEP |
| D1 | GPIO1 | → | DIR |
| D3 | GPIO21 | → | EN |
| 3V3 | — | → | VIO |
| GND | — | → | GND |

Five wires. The TMC2209 has eight other pins on the logic side (DIAG, INDEX, MS1, MS2, etc.) — leave them disconnected for v1; the defaults are fine (1/16 microstepping, STEP/DIR mode, no UART tuning).

### 3. Motor side: TMC2209 → motor

The LDO 42STH48 is a 4-wire bipolar stepper. The wires come in two pairs (one pair per coil). With coil pairs `A` and `B`:

| TMC2209 pin | → | Motor wire |
|---|:-:|---|
| A1 | → | Coil A, end 1 |
| A2 | → | Coil A, end 2 |
| B1 | → | Coil B, end 1 |
| B2 | → | Coil B, end 2 |

If you don't know which two motor wires form a pair, **measure with a multimeter on continuity**: the two within a coil have low resistance (a few Ω), the two across coils have no continuity. LDO motors usually have a wiring diagram on the datasheet that maps the connector pinout; check that first.

### 4. Power: PSU → TMC2209

| 12 V PSU | → | TMC2209 |
|---|:-:|---|
| `+12 V` | (via 3 A inline fuse) | `VM` |
| `GND` | → | `GND` (same as logic GND — single star point) |

If you're using the buck (MP1584 mini or LM2596) for the XIAO instead of USB power, also tap the 12 V into the buck VIN/GND and run the buck VOUT/GND to the XIAO's 5V/GND pins.

### 5. Endstop (only needed for step 5 of success criteria)

| XIAO label | GPIO | → | Endstop |
|---|---|:-:|---|
| D8 | GPIO19 | → | Switch common (`COM`) |
| GND | — | → | Normally-open contact (`NO`) |

The firmware uses `INPUT_PULLUP` with `inverted: true`, so closing the switch pulls GPIO19 to ground and the firmware reads it as "triggered → reset position to 0".

## Set Vref before commanding motion

The TMC2209 has a tiny potentiometer that sets the **per-coil current limit**. Out of the box it's usually set conservatively low; if you skip this you'll get weak / stalling motion.

Procedure:

1. Connect everything *except* the motor (or unplug the motor wires temporarily).
2. Power up 12 V and the ESP32. The driver is now energised but no motor coils are switching.
3. Touch a multimeter probe (set to DC volts) between the TMC2209's `Vref` test point (a small via labelled `VREF`) and `GND`.
4. Adjust the pot with a small flat screwdriver until the multimeter reads about **1.0 V**.
5. Power off, reconnect the motor.

The TMC2209 conversion is roughly `I_rms ≈ Vref × 1.77 × √2 / Rsense_ratio` — the simplified rule of thumb is **Vref ≈ 0.55 × I_rms**, so Vref = 1.0 V → ~1.8 A RMS, which is just above the LDO's 1.68 A rating. Drop to **0.9 V** if the driver gets uncomfortably warm at idle (>70 °C — fingertip "ow" temperature).

## Flash the firmware

```
cp firmware/common/secrets.example.yaml firmware/common/secrets.yaml
# edit secrets.yaml: wifi_ssid, wifi_password, fallback_password,
#                    api_encryption_key (openssl rand -base64 32),
#                    ota_password
esphome run firmware/window-opener.yaml
```

First compile takes 5–10 minutes (ESP-IDF building its toolchain). After the first build, subsequent flashes go over Wi-Fi via OTA.

## Test sequence

In Home Assistant, with the ESPHome integration:

1. **`cover.open_cover` on `cover.window_opener`** → motor should spin away from the closed direction. If it spins the *wrong way*, swap coil pairs `A1↔A2` (or set `dir_pin: { number: GPIO5, inverted: true }` in `firmware/variants/stepper.yaml` and re-flash).
2. **`cover.close_cover`** → motor spins the opposite direction.
3. **`cover.set_cover_position` to 50** → motor runs for half the calibrated stroke and stops. Position attribute in HA shows `50`.
4. **Trigger the endstop manually** (touch a wire from GPIO7 to GND) → HA position attribute jumps to 0.

If all four pass, Phase 1 is done.

## Troubleshooting

| Symptom | Likely cause | Fix |
|---|---|---|
| Motor vibrates / hums but doesn't rotate | Coil pairs miswired (mixed across coils) | Swap any two adjacent motor wires — try `A2 ↔ B1`. |
| Motor moves only one direction | DIR signal stuck or unwired | Re-seat the D1 (GPIO1) wire; multimeter the signal during a `cover.close_cover` action. |
| Motor stalls under modest load | Current limit too low | Raise Vref by 0.05 V at a time, retest. |
| TMC2209 visibly hot (>70 °C at idle) | Current limit too high, or no heatsink, or no airflow | Lower Vref, attach the stick-on heatsink. |
| HA shows the device offline | Wi-Fi creds, encryption key mismatch, or HA can't reach the subnet | Check ESPHome logs (`esphome logs firmware/window-opener.yaml`); verify `secrets.yaml`. |
| ESPHome compile fails on `framework: esp-idf` | First-time toolchain build interrupted | `rm -rf .esphome/` and re-run; first build genuinely takes 5–10 min. |
| TMC2209 dies on first power-up | **Missing 100 µF cap** | Order another driver. Don't skip the cap this time. |
| Position drifts after multiple moves | Steps lost (current too low, speed too high, or mechanical bind) | Lower `max_speed` in `stepper.yaml`; increase Vref; check the lead screw moves freely by hand. |

## Feature test — lock / free-wheel / HA closed sensor (`stepper-uart` variant)

These exercise the firmware feature set added 2026-06-05. Run them at the desk
(bare motor, no window) before mounting. They only apply to
`firmware/variants/stepper-uart.yaml` — the linear-actuator and basic-stepper
variants don't have current-based lock/free-wheel.

### Simulating the window contact on the bench

There's no real window contact on the desk, so fake it with a Home Assistant
helper and point the firmware at it:

1. In HA: **Settings → Devices & services → Helpers → Create → Toggle**, name it
   e.g. *Fake window contact* (`input_boolean.fake_window_contact`).
2. In `firmware/variants/stepper-uart.yaml` set
   `closed_sensor_entity: "input_boolean.fake_window_contact"`, flash.
3. Polarity matches the real convention used in the lambda: **toggle ON = window
   OPEN, toggle OFF = window CLOSED**. (Flip the `!...state` in `window_closed`'s
   lambda if your real sensor is the other way round.)

Watch `esphome logs firmware/window-opener.yaml` throughout — every transition
logs a line.

### Tests

| # | Do this | Expect |
|---|---|---|
| F1 | Flash with the fake contact **ON** (open). Look at `cover.window` position. | Position is **`unknown`** — no homing has happened, and boot is passive (motor does **not** move). |
| F2 | Toggle the fake contact **OFF** (closed). | `window_closed` → on_press fires: position snaps to **0** with **no motor motion** (homed in place). Log: "Homed…". |
| F3 | Toggle contact **ON** (open) again, then call `cover.open_cover`. | Position was known, so it just runs toward open. (If you'd toggled to make position unknown first, the move would **home toward closed first**, then open.) |
| F4 | Call **`lock.lock`** on `lock.window_lock`. | Motor drives to closed (pos 0), then *Window opener — actual current* climbs to ~**900 mA** (the lock clamp). Lock entity shows **locked**. |
| F5 | While locked, call `cover.open_cover` or set position 50. | **Ignored.** Log: "Locked — open/position command ignored". Slider snaps back. `cover.close_cover` is still allowed. |
| F6 | While locked, turn on `switch.window_freewheel`. | **Rejected.** Log: "Cannot free-wheel while locked". Toggle reverts to off on its own. |
| F7 | Call `lock.unlock`. | Hold current drops back to ~**500 mA**; lock shows **unlocked**. |
| F8 | Power-cycle while **locked** (lock first, then unplug/replug). | On boot it actively drives closed and re-clamps to ~900 mA; lock entity comes back **locked**. (Only the locked state moves the motor on boot.) |
| F9 | Unlocked: turn on `switch.window_freewheel`. | *actual current* drops to **0**; the shaft spins **freely by hand** (coils released via `standstill_mode: freewheeling`, 0 mA hold). |
| F10 | While free-wheeling, toggle the fake contact (simulate the sash crossing the closed point), then turn the switch **off**. | Position goes **`unknown`** (move detected). Next `cover.*` command **homes first**, then moves. |
| F11 | While free-wheeling, *don't* toggle the contact, then turn the switch off. | Position is **kept** (no crossing detected → assumed unmoved). Known limitation: a real hand-move that never crosses the contact isn't caught — see `PLAN.md`. |

> **Open-end stall (F-extra):** StallGuard is disabled on the bench (`threshold: 0`)
> because an unloaded motor reads near-stall constantly. The "stall while opening
> → reported full stroke" path is therefore inert until SGTHRS is tuned on the
> real rig — see `docs/build-log.md` "Phase 3 — StallGuard tuning procedure".

## After Phase 1 passes

Move to **Phase 2 — mechanical bring-up**:

- Print both brackets (`mechanical/cad/*.scad`).
- Tap the M6 holes per `mechanical/cad/README.md`.
- Source the remaining mechanical bits (1× LH M6 nut, VHB, M4 screws, fuse holder, hookup wire).
- Design the lead-screw rig brackets (motor mount, far-end bearing block, carriage with rod-end + Prusa nut). These aren't modelled yet — they need physical parts in hand for measurement.

Don't skip Phase 1. Bench-test passes are the only thing that distinguishes "the motor is fine, it's the firmware" from "the firmware is fine, it's the motor" when something later goes wrong on the window.

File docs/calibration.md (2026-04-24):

# Calibration

Once the device is mounted and wired, calibrate the stroke → position mapping. This is what makes the HA `cover` percentage match reality.

## Linear-actuator variant

The `full_stroke_seconds` substitution in `firmware/variants/linear-actuator.yaml` must match the measured time the actuator takes to travel from fully closed (retracted) to fully open (extended) at full PWM, **under load** — i.e. with the window actually attached. Unloaded bench timings are usually 10–20% faster.

Procedure:

1. Close the window fully (handle to the locked position, then unlock to tilt or turn).
2. Command `open` from HA and start a stopwatch.
3. Stop timing when the actuator reaches its mechanical limit (you'll hear the motor stall or see the carriage stop).
4. Repeat 3× and average.
5. Update `full_stroke_seconds` in `firmware/variants/linear-actuator.yaml` and reflash.

Repeat the same procedure in the close direction. If the two numbers differ by more than ~10%, split `open_duration` and `close_duration` in the YAML and give each its own value.

**Drift management.** Time-based tracking drifts after repeated partial moves. A daily automation that closes fully, then opens to the desired position, resets the estimate. Or wire the optional 10-turn pot for closed-loop position.

## Stepper variant

The `steps_full_stroke` substitution in `firmware/variants/stepper.yaml` must match the number of steps from endstop-trigger (closed) to the mechanical open limit.

Procedure:

1. Power on with the carriage somewhere mid-travel. The device reports `unknown` until homed.
2. Command `close` from HA — the carriage drives toward the endstop and zeros.
3. Command `open` and watch the log for the step count when the actuator hits its mechanical open limit (current-based stall or visual confirmation).
4. Update `steps_full_stroke` to a value ~5% below that peak (safety margin so you don't slam the limit on every full-open).
5. Reflash.

**Sanity rule:** if `steps_full_stroke` changes by more than ±10% between runs on the same hardware, something is slipping — check the coupler set screws and the lead-screw support bearings.

## Common to both variants

- Calibrate in the window mode you use most often (tilt). Turn mode uses a longer arc of the stroke, so the same stroke time/steps naturally maps to a smaller % in turn — this is fine; HA still sees 0–100.
- Re-calibrate after any mechanical change (bracket replacement, rod-end swap, actuator swap).
- If 0% doesn't fully close the window physically, the actuator is undersized or the geometry is off — don't paper over it in firmware.

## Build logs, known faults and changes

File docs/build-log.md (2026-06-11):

# Build log

Tracks parts ordered, prices paid, and assembly progress. The repo's `hardware/BOM.md` is the *spec*; this file is the *as-built* record.

## Variant chosen

**Variant B — Stepper + lead screw.** Decided in late April 2026 based on parts availability and pricing in Romania.

## Parts ordered

### Mechanical — lead-screw drive

| Part | Vendor | Price (RON) | Status |
|---|---|---:|---|
| Tr8 trapezoidal lead screw, 8 mm pitch, 400 mm | TBD | 34.99 | ✅ |
| Prusa MK3 brass nut, Tr8x8 | TBD | 18.12 | ✅ |
| Generic Tr8x8 trapezoidal nut × 2 | TBD | 29.00 (set) | ✅ |
| KP08 pillow-block bearing × 2 | TBD | 24.00 (set) | ✅ |
| Rod-end M6 RH (CS10, MGK) | [rulmentika.ro](https://www.rulmentika.ro/) | 14.00 | ✅ |
| Rod-end M6 LH (CSL10, MGK) | [rulmentika.ro](https://www.rulmentika.ro/) | 14.00 | ✅ |
| **Subtotal** | | **134.11** | |

### Stepper

| Part | Vendor | Price (RON) | Status |
|---|---|---:|---|
| LDO-42STH48-1684MAC NEMA17 (0.9°, 1.68 A) | TBD | TBD | ✅ |
| Flexible coupler 5 mm → 8 mm × 2 (1 spare) | TBD | 21.42 | ✅ |
| BIGTREETECH TMC2209 V1.3 × 2 (1 spare) | TBD | 73.98 | ✅ |
| Creality mechanical endstop × 2 (1 spare) | TBD | TBD | ✅ |

### Power & support

| Part | Vendor | Price (RON) | Status |
|---|---|---:|---|
| LM2596 DC-DC step-down regulator × 4 (kept as spares — MP1584 mini chosen for the build) | TBD | 37.48 | ✅ |
| MP1584-style mini buck (~22 × 14 mm, 12 V → 5 V) | drawer | — | ✅ |

### Spares / parts ordered but not used in this build

| Part | Vendor | Price (RON) | Note |
|---|---|---:|---|
| Flexible coupler 5 mm → 5 mm | TBD | 9.06 | Doesn't fit this build (motor shaft is 5 mm but lead screw is 8 mm). Save for a future project. |

### Running totals

- Mechanical (lead-screw + nuts + bearings + rod-ends): **134.11 RON**
- Stepper + coupler + driver + endstops: motor TBD + endstops TBD + **95.40 RON**
- Power: **37.48 RON**
- (Spares: 9.06 RON not counted)

### Already on hand (drawer)

| Part | Note |
|---|---|
| Seeed Studio XIAO ESP32-C6 | User has spares from prior projects. Chosen over classic ESP32 to keep Matter/Thread on the table, and over the DevKitC-1 for the smaller form factor. Firmware uses ESP-IDF framework + GPIO 1/2/21/19 (XIAO labels D1=DIR, D2=STEP, D3=EN, D8=endstop). |
| Configurable bench PSU | Used for Phase 1 bench testing instead of a fixed AC-DC brick. Set 12 V, 1 A limit for first power-on, 3 A limit for normal operation. A dedicated 12 V / 5 A AC-DC brick can wait until Phase 2 (window install). |
| 470 µF / 35 V electrolytic cap | Used in place of the 100 µF / 25 V called out in the wiring docs. Higher capacitance + higher voltage rating = more headroom; common 3D-printer modding upgrade. ≥100 µF is the spec, more is better. |
| Hookup wire | Mixed lengths / colours of 22 AWG silicone wire. Sufficient for bench + window runs. |
| Motor pigtail | The LDO motor shipped with a JST-XH 4-wire pigtail. Either cut the connector off and screw bare wires into the TMC2209, or use an XH-to-XH cable. |

### Phase 1 bench-test readiness

✅ **Ready to bench-test.** All Phase 1 parts on hand (motor, driver, cap, ESP32-C6, PSU, wires). Follow `docs/bench-test.md`.

### Still to order — for Phase 2 (window install)

- [ ] **1× LH M6 nut** for the LH rod-end (rulmentika.ro or specialty fasteners — needed because standard RH nuts won't thread onto the CSL10's left-hand shank). *Or* skip the LH rod-end and buy a 2nd RH (CS10) instead.
- [ ] **Dedicated 12 V / 5 A AC-DC PSU** (for permanent install — once the bench test passes and the rig is going onto the window).
- [ ] 3M VHB 4950 / 5952, 19 mm × ~1 m
- [ ] M4 × 16 self-tapping screws (~8 pcs)
- [ ] Inline 5 A blade fuse holder + fuses (for the permanent install)
- [ ] Filament for 3D-printed brackets + lead-screw rig (PETG or ABS, ~250 g total)
- [ ] (optional) 8 mm smooth steel rod for carriage anti-rotation (~150 mm length, will source after rig CAD is finalised)

## Sanity-check on what was bought

### Lead screw & nut compatibility

The Prusa MK3 lead screws are **Tr8x8** (4-start, 2 mm pitch, 8 mm/rev), so the "Prusa MK3 nut" matches the Tr8 / 8 mm-pitch screw. The two generic Tr8x8 nuts are spares + can be used for an **anti-backlash double-nut** configuration on the carriage if turn-mode position needs more precision.

### Stepper torque vs Tr8x8 lead

LDO-42STH48-1684MAC: 0.9° step, 1.68 A rated, ~0.45 N·m holding torque.

Theoretical linear force on a Tr8x8 screw:
> F = 2π · τ / lead = 2π · 0.45 / 0.008 = **353 N (theoretical)**
> at 30–50 % real efficiency = **105–175 N**

Earlier spec called for ≥500 N. With these parts, expect:

- **Tilt mode** (needs <50 N): comfortable headroom. ✅
- **Turn mode** (needs ~150–250 N for a typical 20 kg sash): borderline, may stall under load.

**Mitigation if turn stalls:**
1. Try first — friction estimates are very rough; many windows turn with <100 N once the seal is broken.
2. If insufficient, swap the Tr8x8 lead screw for a **Tr8x4** (half the speed, ~2× the force). The motor, nut, and bearings stay the same.

### KP08 bearings

KP08 = pillow-block bearing with an 8 mm bore. Two of them support both ends of the lead screw (one near the motor, one at the far end), keeping the screw concentric and preventing it from whipping. Standard for DIY linear actuators.

## Mechanical CAD still to design

The stepper variant needs more 3D-printed parts than the linear-actuator variant. Items to add to `mechanical/cad/`:

- [ ] **Motor mount** — holds NEMA17 to one end of the assembly; aligns with one KP08 bearing.
- [ ] **Far-end bearing block bracket** — holds the second KP08 at the opposite end of the lead screw, including a way to anchor that end to the fixed frame bracket.
- [ ] **Carriage** — slides along the lead screw via the brass nut (M3 mounting pattern from the Prusa MK3 nut). Holds the rod-end at one end. Optional anti-backlash double-nut housing.
- [ ] **Outer rail / linear guide** (optional) — keeps the carriage from rotating with the screw. Could be a printed slot on a parallel rod, or rely on the rod-end constraint at the moving end.

These come after the user has the parts in hand and can measure the actual nut and bearing dimensions.

## Assembly progress

- [x] Phase 0 — Repo scaffolded
- [x] **Phase 1 — Bench prototype passed 2026-05-08** (XIAO + TMC2209 + LDO motor on the desk; HA discovered `cover.window_opener`; open/close/% all working).
- [x] **Phase 1.5 — UART upgrade passed 2026-05-11**. R10 bridged on driver, 1 kΩ on TX line, DIAG wire from driver → XIAO D9 for hardware-interrupt stall detection. `firmware/variants/stepper-uart.yaml` is the active variant. Software currents (1100/500 mA), motor_load + actual_current sensors, temperature-band sensor all working.
- [x] **Firmware feature pass 2026-06-05** (full feature set on `stepper-uart.yaml`). Added: auto-homing on boot + on-demand (position `unknown` until first home); **closed detection from the window's own HA contact sensor** (`closed_sensor_entity` substitution; D8 micro-switch left commented, not installed); **lock** entity (drive-closed + 900 mA clamp, refuses open while locked, persists across reboot); **free-wheel** switch (releases coils via `standstill_mode: freewheeling` + 0 mA hold — not `tmc2209.disable`, which won't compile under current ESPHome — hand-movable, marks position unknown if the sash crosses the closed sensor while free); open-end via StallGuard hard-stop. **Not yet flashed/tested on hardware** — desk re-test pending. Set `closed_sensor_entity` to the real HA entity before flashing.
- [ ] Phase 2 — Mechanical assembly (lead-screw rig, dry-fit on window)
- [ ] Phase 3 — Tuning + HA integration on real window
- [ ] Phase 4 — Polish (enclosure, automations, CAD STLs released)

## Phase 2 — Open-travel calibration (set "fully open")

There is **no open-end switch**. "Fully open" is dead-reckoned: the firmware
counts microsteps from the closed home (position 0) up to `steps_full_stroke`,
then stops. That number **must match the rig's real usable travel**, or one of
two bad things happens:

- `steps_full_stroke` **too large** → the motor keeps driving past the real end
  and rams the mechanical hard stop (until StallGuard is tuned to catch it).
- `steps_full_stroke` **too small** → "100% open" stops short of the real max.

`steps_full_stroke` and `microsteps` live in `firmware/window-opener.yaml`
(they override the variant). Scale factor: **µsteps/mm = 50 × microsteps**
(50 = (360/0.9 steps-per-rev) ÷ 8 mm-per-rev for the Tr8x8). So at microsteps
16 → 800 µsteps/mm; at 8 → 400.

Procedure, once the rig is mounted and homed:

1. **Home** (window closed, contact reports shut → position 0).
2. **Free-wheel** the motor (`switch.window_freewheel`) and **push the sash by
   hand to the maximum opening you actually want** (tilt fully open, or the turn
   angle you'll use). Measure the actuator travel from closed to here, in mm —
   call it `T`. (Or compute from geometry in `docs/window-spec.md`.)
3. Re-engage, set **`steps_full_stroke = round(T × 50 × microsteps)`**.
   Example: T = 180 mm at microsteps 16 → 180 × 800 = **144000**.
4. Flash, home, then command **`cover.open_cover`**. Verify it reaches the
   intended max and stops **without** straining against the end. Trim the number
   down 1–2% if it bottoms out hard.
5. Sanity-check 50%: `cover.set_cover_position 50` should land at ~`T/2` mm.

> Leave a small safety margin: set `steps_full_stroke` a few mm short of the
> absolute mechanical limit so normal full-open never relies on hitting the
> hard stop. StallGuard (next section) is the *backstop* for lost steps /
> obstructions, not the everyday end-of-travel signal.

### Manual calibration buttons (no sensor / no StallGuard)

Two HA buttons let you set the references by hand from wherever the actuator is:

- **Set CLOSED home (0%) here** — declares the current position as 0.
- **Set OPEN limit (100%) here** — captures the current step count as full stroke
  (`g_full_stroke`). Live-only: it resets to the `steps_full_stroke` substitution
  on reboot. Once you've found the right count, write it into `steps_full_stroke`
  in `window-opener.yaml` to make it permanent.

Flow on the mounted window:
1. Jog the window (cover slider, small steps) until **physically closed** → press
   *Set CLOSED home (0%)*.
2. Jog until **physically fully open** — gently, StallGuard is off so there's no
   over-travel/obstruction protection → press *Set OPEN limit (100%)*.

These capture the **motor's step count**, which only tracks motor-driven motion.
Moving the sash by hand in free-wheel does **not** update it, so press the
buttons only after positioning via the motor (or right as the sash crosses the
closed contact). Good for first calibration before StallGuard/contact are dialed.

### Sensorless mode (`homing_mode: sensorless`)

If you set `homing_mode: sensorless` (no contact sensor), the above changes:

- **Closed** isn't sensed — it's found by ramming the stop until StallGuard
  trips, at the gentle `homing_current`. **Requires `stall_threshold` (SGTHRS)
  tuned > 0 first** (see the StallGuard section) or homing never completes.
- **Open** isn't a fixed number — the firmware *learns* it from the
  opening-direction stall into the runtime `g_full_stroke`. After homing,
  **command one full `cover.open_cover`** so it learns the stroke before you use
  intermediate positions; otherwise a mid-position command can mis-learn a short
  stroke. `steps_full_stroke` is then only the *initial guess* / overshoot target.
- Trade-offs (rams stops every home, can't tell obstruction from end, SGTHRS
  must be re-tuned whenever you change speed/current) are why `contact` is the
  default. See PLAN.md.

## Phase 3 — StallGuard tuning procedure (do this once mounted)

StallGuard is currently disabled (`tmc2209.stallguard: { threshold: 0 }` in `firmware/variants/stepper-uart.yaml`) because at the bench with no mechanical load the chip can't distinguish "free running" from "stalled" — SG_RESULT pins near 0 either way. Once the motor is on the lead-screw rig with the carriage and rod-ends loaded, retune as follows:

1. **First run, keep `threshold: 0`.** Run a few full open + close cycles via HA so motion completes without spurious stall trips.
2. **Watch `motor_load` in HA.** Ignore the accel/decel spikes — look for the **max reading during the constant-velocity middle portion** of motion. Call that **M** (expect 40-70% under typical sash + seal friction).
3. **Compute SGTHRS** for trip 30 points above the floor:
   ```
   target_SG = 510 * (1 - (M + 30)/100)
   SGTHRS    = target_SG / 2
   ```
   Example: M = 50% → SGTHRS = (510·0.2)/2 = **51**.
4. **Edit the YAML**, change `threshold: 0` to the computed value, flash, retest.
5. **Verify**: normal motion completes without `Stall detected — stopping window`. Manually pinching the carriage / running into the closed-handle hard stop should fire it within ~½ s. If it false-trips during normal motion, bump SGTHRS down ~10 and retry.

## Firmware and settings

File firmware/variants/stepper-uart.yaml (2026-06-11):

# Variant: NEMA17 stepper driven by a TMC2209 in UART mode.
#
# Closely follows the slimcdk component author's reference config:
# https://github.com/slimcdk/esphome-custom-components/blob/master/esphome/components/tmc2209/README.md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
#
# Wiring (XIAO ESP32-C6 → BTT TMC2209 V1.3 pads):
#   3V3                       → VIO
#   GND                       → GND (logic + motor power common)
#   D1  (GPIO1)               → DIR
#   D2  (GPIO2)               → STEP
#   D3  (GPIO21)              → EN
#   D6  (GPIO16) + 1 kΩ       → driver TX  (UART, see note below)
#   D7  (GPIO17)              → driver RX  (UART, no resistor)
#   D8  (GPIO19)              → endstop switch COM
#   D9  (GPIO20)              → driver DIAG  (optional but strongly recommended
#                                             for working stall detection — see
#                                             diag_pin: line below)
#
# BTT V1.3 R10 must be bridged (factory NC) before TX pad is electrically live.
# See hardware/wiring/stepper.md for the R10 detail and the 1 kΩ rationale.
#
# Pin map: hardware/wiring/stepper.md
#
# ─────────────────────────────────────────────────────────────────────────
# FEATURE SET (TMC2209/UART-specific — not portable to the linear-actuator
# variant, which has no current control or freewheel concept):
#
#   • Homing            — drives toward the closed end until the closed signal
#                         trips, then zeroes. Boot is PASSIVE: no auto-motion
#                         (a power blip won't slam an open window shut). On boot
#                         position is `unknown` and is recovered for free the
#                         moment the closed contact reports shut (zeroes in
#                         place), or by a homing sweep before the first move if
#                         still unknown. Locked state is the one exception — it
#                         actively drives closed on boot to re-clamp. Position
#                         reads `unknown` in HA until homed (CLAUDE.md invariant).
#   • End detection     — selected by the `homing_mode` substitution:
#                           contact    (default): home CLOSED from the window's
#                             OWN HA contact sensor (${closed_sensor_entity});
#                             OPEN is the calibrated step count (g_full_stroke),
#                             with StallGuard only an obstruction backstop.
#                           sensorless: no contact. Home CLOSED by ramming the
#                             stop at a gentle current until StallGuard trips,
#                             and LEARN the OPEN end from the opening-direction
#                             stall. REQUIRES a tuned stall_threshold (> 0).
#                         (Printed D8 endstop is left commented for when added;
#                         in contact mode, homing depends on the HA connection.)
#   • Lock              — `lock.window_lock`. Drives fully closed, then holds
#                         energized at ${lock_hold_current} so the screw
#                         resists back-driving. Open/position commands are
#                         refused while locked (closing is still allowed).
#                         The manual handle remains the real mechanical lock.
#   • Free-wheel        — `switch.window_freewheel`. Releases the coils
#                         (standstill_mode: freewheeling, 0 mA hold) so the
#                         window can be moved by hand. While free-wheeling,
#                         a transition of the closed signal means the sash was
#                         physically moved → position is marked unknown and the
#                         next command re-homes first. NOTE: a bare TMC2209 has
#                         no rotor feedback, so hand-movement that never crosses
#                         the closed sensor cannot be detected — re-engaging
#                         then keeps the last position. Add an encoder if that
#                         matters. Cannot be enabled while locked.
#   • Home now          — `button` "Home now (drive to closed)" runs the homing
#                         sweep on demand (move_to only auto-homes when position
#                         is unknown). Drives the motor.
#   • Manual calibration— two `button` entities: "Set CLOSED home (0%) here" and
#                         "Set OPEN limit (100%) here". Capture the current motor
#                         step count as the closed (0) / open (full-stroke)
#                         reference, so you can teach both ends by jogging to
#                         them — no contact sensor or StallGuard needed. The
#                         open scale is live-only (resets to steps_full_stroke on
#                         reboot). Captures motor-driven position only, not hand
#                         movement in free-wheel.
# ─────────────────────────────────────────────────────────────────────────
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

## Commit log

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2026-04-24 Add mounting-geometry diagram (SVG)
    Three-panel schematic: front view (closed), tilt cross-section, turn
    top-down. Shows the fixed-end anchor at the bottom-hinge corner and the
    moving-end anchor at the opposite sash corner. Referenced from README
    and mechanical/README so it renders on the GitHub repo page.
2026-04-24 Rework mounting geometry after kinematic review + real measurements
    The original "anchor at the bottom-hinge corner" plan was wrong: that
    point sits on both the tilt and turn pivot axes, so the actuator
    distance is conserved in both modes and can't drive either. Replaced
    with: fixed end at top-middle of frame, moving end on top rail of sash
    120 mm from the hinge. Both endpoints are now off both axes.
    Target window measured (W=845, H=1325 mm), yielding actuator spec of
    200 mm stroke / ≥500 N. Also documents the mode-asymmetry consequence:
    full tilt = ~26% stroke, full turn = ~78% stroke, so the `cover` entity
    exposes raw stroke % and HA handles per-mode semantics.
    Added docs/window-spec.m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
2026-04-24 Add side-view and bottom-up photos; document mounting surface
    Two new reference photos confirm: frame profile is ~70 mm deep with a
    clean room-side face for the fixed-end bracket, and the hinge-side wall
    reveal (~15-20 cm) gives the sash plenty of room to swing past 90° in
    turn mode. Fly screen is on the outside and does not constrain us.
2026-04-24 Add mounting cross-section diagram
    Side cut through the top-middle of the frame showing where the
    fixed-end bracket attaches (room-side face of the top frame rail),
    bracket protrusion, rod-end ball joint, and the actuator body
    extending horizontally toward the hinge side. Referenced from
    mechanical/README.md so the mounting plan is self-explanatory.
2026-04-24 Update mounting detail for 20 mm sash protrusion
    The sash sits ~20 mm proud of the frame's inside face, so the fixed-end
    bracket must mount entirely above the sash top level — otherwise the
    arm would collide with the protruding sash. Updated mounting-detail.svg
    to show this constraint, added the sash protrusion to window-spec.md,
    and documented the bracket-placement rule in mechanical/README.md.
2026-04-24 Fix mounting detail: only 20 mm of frame face is accessible
    The sash covers most of the frame's inside face. The only exposed
    mounting surface is a 20 mm strip between the sash top and the
    ceiling. Updated cross-section diagram to show this, and added a
    hook-over-the-frame-top to the bracket so mechanical load path does
    not depend solely on VHB + 2 small M4 screws in the stall case.
2026-04-24 Add sash-end mounting cross-section; lock in 190 mm bracket width
    Measurements in: sash and frame are both 80 mm thick/deep, sash lip
    is 20 mm, frame visible strip is 20 mm. Brackets are 190 mm wide along
    the window. Added docs/mounting-detail-sash.svg showing that the
    sash-end bracket has plenty of mounting area (190 × 42 mm), so the
    M6 rod-end threads directly through the plate — no hook needed, no
    separate arm geometry. Load analysis inline in the diagram shows ~3×
    margin on VHB at stall force, vs ~2× over the limit on the fixed end.
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2026-04-24 Add OpenSCAD sources for both brackets; fix peel-stress analysis
    mechanical/cad/:
    - common.scad: shared parameters (hole sizes, bracket width, window dims)
    - sash-bracket.scad: 190 × 45 × 5 mm plate with central M6 boss and four
    corner M4 holes; back face is flat for VHB
    - frame-bracket.scad: 190 × 18 × 5 mm plate with a 27 mm arm for the
    rod-end, 2 mm ceiling-jam tab at the top edge, two M4 holes
    - README.md: install, render, print, and post-print tapping notes
    Corrected peel-stress analysis in both mounting-detail SVGs and in
    mechanical/README.md. The earlier calculation treated the actuator
    force as vertical, bending the plate about a horizontal axis (18 mm
    dimension) — that ga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
    [common.scad, frame-bracket.scad, sash-bracket.scad]
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2026-04-27 Fix sash-bracket CAD: remove the spurious cylindrical boss
    The sash-bracket SCAD file had a 20 × 10 mm cylindrical boss around the
    M6 hole — a leftover from when I was worrying about thread engagement.
    It contradicted the cross-section in mounting-detail-sash.svg and the
    mechanical/README.md text, both of which describe a flat plate with the
    rod-end shank threading through and a nut on the back.
    Replaced the boss with a hex pocket on the BACK face (M6 across-flats
    + a hair of clearance, 4 mm deep), so the M6 nut sits flush and does
    not poke into the sash. Updated the print orientation in cad/README.md:
    the sash bracket now prints back-face-UP so the pocket prints as a
    clean cavity. Added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
    [sash-bracket.scad]
2026-04-27 Add rendered STLs and PNG previews for both brackets
    mechanical/stl/sash-bracket.stl (127 KB binary, 2540 facets)
    mechanical/stl/frame-bracket.stl ( 33 KB binary, 660 facets)
    mechanical/stl/{sash,frame}-bracket.png — preview renders shown on
    the GitHub repo page so the geometry is visible without installing
    OpenSCAD locally.
    Both rendered with openscad@snapshot 2026.04.26 (the brew cask with
    Apple Silicon native support — the deprecated `openscad` cask is
    Intel-only and fails macOS Gatekeeper). cad/README.md updated with
    the binary-STL flag and a macOS-specific install note.
    [frame-bracket.stl, sash-bracket.stl]
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2026-05-06 Update KP08 + Prusa-nut dimensions from caliper measurements
    KP08 (measured 2026-05-06):
    - Base length 54 mm (was 50)
    - Body width along axis 30 mm (was 21)
    - Mounting hole c-to-c ≈ 39 mm derived from 47 mm outer-to-outer
    (slot length ~8 mm subtracted)
    - M5 hole clearance bumped to 6.5 mm to fit the slot
    - Bore-centre height kept at standard 17 mm — not directly measured
    in the photos, will need to verify before printing
    Prusa MK3 nut (measured 2026-05-06):
    - Flange OD 19 mm (was 22)
    - Total length 14.7 mm (was 15)
    - Flange thickness 5.7 mm derived from total − body length (was 3.5)
    - M3 hole spacing 12.1 mm across opposite holes (was 16) —
    this is significantly tighter than t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
    [common.scad, rig-carriage.stl, rig-far-bearing.stl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]
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2026-05-11 UART variant: stabilise on dev's reference + document BTT V1.3 R10/DIAG quirks
    Working through StallGuard-on-bench debugging exposed two real
    issues — both now baked into the firmware + wiring docs:
    - BTT V1.3 ships with R10 unpopulated, so the driver's TX pad is
    dead until bridged (factory manual p.7). Without bridging only
    half the UART link works; with bridging the slimcdk component
    also needs a 1 kΩ in series on the MCU TX line for contention
    protection.
    - Stall detection in slimcdk only works reliably when diag_pin is
    wired to a real GPIO (hardware interrupt path). Without it the
    component falls back to polling IOIN over UART inside loop(),
    which gets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
    [stepper-uart.yaml]
2026-05-11 StallGuard: confirm DIAG interrupt path works; defer threshold tuning to Phase 3
    DIAG wire from driver to XIAO D9 is in; firmware boots with
    "Stall detection: DIAG interrupt raises flag". Verified the
    interrupt fires by overshooting the threshold (motor stopped
    on first move).
    At the bench with no mechanical load the chip can't distinguish
    free-running from stalled — SG_RESULT pins near zero either way,
    so any non-zero SGTHRS false-trips on every move. Setting SGTHRS
    to 0 here disables stall-via-DIAG (driver-error path still active
    via on_status) until real load is present.
    Also added TCOOLTHRS = 400000 so that once SGTHRS is bumped back
    up, the chip will actually assert DIAG for stalls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
    [stepper-uart.yaml]
2026-05-13 stepper-uart: comment out diagnostic sensors that were starving step pulses
    Each TMC2209 register read blocks the main thread for ~1-2 ms, and the
    slimcdk stepper generates STEP pulses on the same thread. With 6 sensors
    polling at 250 ms the cumulative UART time slowed the motor to a crawl.
    motor_load remains active at 1s for routine HA visibility; the rest are
    left in the file as commented-out blocks so they can be re-enabled (and
    their intervals dropped to ~250 ms) when we tune StallGuard on the rig.
    [stepper-uart.yaml]
2026-05-13 CAD: spec-sheet calibration + slim down printed blocks + add assembled view
    Calibrate common.scad against the official datasheets (links provided
    by user):
    - KP08 pillow block (grema3d KP08 spec):
    H 17 → 14 (bore-centre height above base — fixed 3mm misalignment)
    A → 13 (width along bore — was implicitly 54, an order-of-
    magnitude error that made the bearings look chunky)
    L 54 → 55
    J 39 → 42 (bolt-hole spacing)
    H2 33 → 28 (total height)
    - Prusa MK3 brass nut (piese3d spec):
    Flange OD 19 → 25 (19 was actually the bolt-circle Ø)
    Flange thk 5.7 → 4
    Body OD 10.2 → 10
    Bolt circle —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
    [common.scad, rig-assembled.scad, rig-carriage.scad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]
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2026-05-13 SketchUp .skp: consolidate printable parts into single named groups (v5)
    Previous .skp split each printable part into 2-3 sub-groups
    (Motor_mount_back_plate / _floor / _rod_end_tab, etc.) which made it
    hard to see "this is the motor mount" as a unit. Rebuild so each
    printable part is ONE group, named to match the .scad/.stl file:
    - frame-bracket
    - sash-bracket
    - rig-motor-mount (now includes the two L-corner gussets that
    were missing in v4)
    - rig-far-bearing
    - rig-carriage
    Off-the-shelf hardware also consolidated (KP08-1/-2 as a single group
    each, Prusa-MK3-brass-nut as one group, both rod-ends as one group
    each). 23 groups total: 9 window + 5 printable p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
    [window-opener-rig.skp]
2026-05-13 Fix KP08 mounting holes: rotate cylinder to actually pass through floor
    The motor mount and far-bearing SCAD had the KP08 mounting holes
    defined as default-orientation cylinders (OpenSCAD's cylinder() is
    along +Z). The floor's thickness, however, is along Y, so the cylinder
    poked the *side* of the floor instead of through its thickness — the
    "scoop" the user saw in OnShape when loading the STL.
    Fix: rotate the cylinder by -90° around X so its axis runs vertically
    (along local Y, matching floor thickness) BEFORE subtracting from the
    floor. Now KP08_HOLE_SPACING / KP08_HOLE_D produce real Ø5.5 M5
    through-holes positioned at ± J/2 from the bore axis, perpendicular
    to the lead screw.
    STLs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
    [rig-far-bearing.scad, rig-far-bearing.stl, rig-motor-mount.scad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]
2026-05-13 rig-motor-mount: add access slots for the bottom 2 motor bolts
    The motor's M3 mounting holes sit at Y = ±NEMA17_HOLE_SPACING/2 = ±15.5
    on the back plate. Floor top at Y = FLOOR_TOP_Y = -14, so the lower
    two motor holes (Y = -15.5) live inside the floor's Y range
    (-20 to -14) — the bolt heads and driver have nowhere to go.
    Fix: cut two 12 × 6 × 8 mm rectangular slots through the floor at
    Z = ±NEMA17_HOLE_SPACING/2 = ±15.5, starting at X = 0 (back plate
    face) and extending 12 mm forward. A screwdriver can now reach the
    bottom bolts from outside the rig.
    STL + PNG re-rendered; rig-assembled-iso.png regenerated to pick up
    the change.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
    [rig-motor-mount.scad, rig-motor-mount.stl]
2026-05-13 rig-motor-mount: motor sits on floor; KP08 raised on pedestal
    The previous design cantilevered the motor off the back plate with the
    KP08 mounting floor at lead-screw - bore-height. That floor sat right
    in the path of the motor's lower 2 corners and blocked the lower 2
    M3 mounting bolts. Access slots were a workaround but invalid: the
    motor body itself can't seat against the back plate with the floor in
    the way.
    Redesign:
    - Drop FLOOR_TOP_Y to -NEMA17_FACE/2 = -21.15 so the motor body's
    bottom corners rest on the floor and all 4 M3 holes are clear.
    - Add a 7.15 mm pedestal under the KP08 to restore bore-to-shaft
    alignment now that the floor is below the KP08's natural seat.
    - Extend the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
    [rig-motor-mount.scad, rig-motor-mount.stl]
2026-05-13 rig-motor-mount: shrink part; push KP08 past coupler
    The previous KP08_START_X = NEMA17_SHAFT_L + 2 = 26 left only 8 mm
    between the motor shaft tip and the KP08 bore entry - not enough for
    the 25 mm Tr8 coupler, which would collide with the KP08 pedestal.
    - Push KP08_START_X to 32 mm: shaft_tip (18) + (COUPLER_L -
    COUPLER_MOTOR_GRIP) + 1 mm clearance. The coupler's +X end now sits
    1 mm short of the KP08 base.
    - Shrink MOTOR_FLOOR_EXT from 50 mm (full motor body length + 2) to
    25 mm (matches GUSSET_LEG). The 4 M3 bolts in the back plate carry
    the motor weight; the floor only needs to support the motor's first
    few millimetres near the L-corner. Net X length: 107 mm -> 80 mm.
    - Tight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
    [rig-motor-mount.scad, rig-motor-mount.stl]
2026-05-13 rig-motor-mount: full motor body support + restore rod-end tab
    The previous design only supported the first 25 mm of the motor body
    on the floor; the remaining 23 mm cantilevered into thin air past the
    floor's -X edge. The rod-end tab was also deleted, leaving the rig
    with no way to attach to the frame bracket.
    - Extend MOTOR_FLOOR_EXT to NEMA17_BODY_L + 2 = 50 mm so the floor
    carries the full motor body, plus 2 mm of clearance to the rear wall.
    - Add a rear-wall column (6 mm thick, Z-width = tab) at the -X end of
    the floor, rising from FLOOR_TOP_Y up to SHAFT_Y + 9 to anchor the
    rod-end tab to the floor.
    - Restore the rod-end tab: 20 mm long x 18 x 18 cross section,
    extending in -X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
    [rig-motor-mount.scad, rig-motor-mount.stl]
2026-05-13 Add rig-assembled.stl - single mesh of the whole rig
    Combines all printable parts in their final positions plus stand-ins
    for motor / screw / KP08 / nut / rod-ends, in one STL for visualization
    in a viewer that doesn't speak OpenSCAD. Manifold (genus 19), 9.3k
    vertices.
    Per-part STLs remain the source-of-truth for slicing - the assembled
    STL is not for printing (it bakes in non-printable hardware stand-ins).
    [rig-assembled.stl]
2026-05-13 rig: rod hole spans full bracket, fix far-bearing rod hole, drop .skp
    Motor mount:
    - Add a 14 mm wide rod sleeve hanging below the floor, running from the
    rear wall (X = -62) to the floor's +X end (X = 49) at Y = -30. Merges
    with the back plate's downward extension. Rod bearing length goes
    from 6 mm (back plate alone) to ~111 mm.
    - Lengthen the rod-hole cylinder so it spans the whole sleeve and exits
    cleanly at both +X and -X ends.
    Far bearing:
    - The end wall was sized from FLOOR_TOP_Y (-14) upward, but the rod
    hole sits at Y = -30 - the cylinder was cutting through air. Extend
    END_WALL_BOT_Y down to -ANTI_ROT_OFFSET - 5 = -35 so the rod hole
    actually drills through material.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
    [rig-assembled.stl, rig-far-bearing.scad, rig-far-bearing.stl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]
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2026-05-13 rig-carriage: enclose rod hole, raise SHAFT_Y, offset M6 tap in Z
    Three coupled fixes:
    1. Rod hole drilling air. The body was 0-36 in Y with SHAFT_Y = 21.6,
    placing the anti-rot rod hole at Y = -8.4 - outside the body. The
    cylinder cut nothing. Drop SHAFT_Y to live higher in a taller body so
    the rod hole sits inside material.
    2. M6 tap vs lead-screw bore overlap (pre-existing). At SHAFT_Y = 21.6
    the bore bottom was 16.6 and the 18 mm M6 tap reached 18 - a 1.4 mm
    intersection. With SHAFT_Y = 35 the tap top sits 12 mm below the
    bore.
    3. M6 tap vs rod hole conflict (newly exposed). Both were at the
    carriage centerline in Z, so the rod-end shank and the steel rod
    would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
    [rig-assembled.stl, rig-carriage.scad, rig-carriage.stl]
2026-05-14 sash-bracket: shift M6 hole 11 mm to match carriage M6 tap offset
    The carriage's M6 tap is offset by -11 mm in carriage-local Z (=
    M6_TAP_Z_OFFSET in rig-carriage.scad) so it clears the anti-rotation
    rod hole. For the rod-end's body to hang straight when the rig is
    assembled, the sash bracket's M6 clearance hole must land at the
    same world Z = -11.
    In sash-bracket.scad's local frame, the plate is rotated [-90,0,0] in
    the rig assembly, mapping local +Y to world -Z. So the M6 hole shifts
    +11 mm in local Y. The original PLATE_H = 45 left no clearance to the
    top-row M4 corner holes after the shift, so grow the plate to 56:
    PLATE_H_BASE = 45 (unchanged symmetric base)
    M6_HOLE_OFFSET = 11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
    [rig-assembled.stl, sash-bracket.scad, sash-bracket.stl]
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2026-05-19 mechanical/v2: add single-mesh assembled STL
    Renders v2-assembled.scad as a manifold STL (378 KB, 7568 facets)
    combining both printed brackets with the off-the-shelf stand-ins
    (NEMA17, U-joint, Tr8 lead screw, Prusa brass nut) in their
    closed-window positions. For visualization in any STL viewer that
    doesn't speak OpenSCAD; per-part STLs remain the source-of-truth
    for slicing the brackets.
    [v2-assembled.stl]
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2026-06-05 mechanical/v2: rework frame-nut-gimbal into pin-assembled 3-piece design
    Redesign the frame nut gimbal as base+posts / outer-yoke / nut-block,
    joined by 4× Ø3 steel dowel pins (short enough to clear the screw bore
    at the gimbal centre). Resize the nut block to contain the Prusa nut's
    bolt circle and the yoke cavity to fit the yawed block. Assembled view
    now draws the pins (show_pins=true). Regenerate STLs/PNGs.
    Also add exploratory gimbal sketches (option1/option3) under
    cad/sketches/.
    [frame-nut-gimbal.scad, frame-nut-gimbal.stl, option1-block.stl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]
2026-06-05 firmware: lock, free-wheel, HA closed-sensor homing on stepper-uart
    Full feature pass on variants/stepper-uart.yaml (now the active variant in
    window-opener.yaml):
    - Closed detection from the window's own HA contact sensor
    (closed_sensor_entity substitution). The D8 micro-switch is not installed —
    its block is left commented, ready to OR back into window_closed.
    - Passive homing on boot (no auto-motion; a power blip won't slam an open
    window shut). Position is `unknown` until the contact reports shut (zeroes
    in place) or the first move triggers a homing sweep. Locked state is the
    exception: it drives closed and re-clamps on boot.
    - Lock entity (lock.window_lock): drive-closed +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
    [stepper-uart.yaml]
2026-06-05 firmware: rename goto script to move_to (goto is a reserved ESPHome id)
    ESPHome reserves the id `goto`, so the motion-entry script failed validation.
    Renamed the script and all references (execute/wait/stop). Config now compiles.
    [stepper-uart.yaml]
2026-06-05 firmware: free-wheel via standstill current, not tmc2209.enable/disable
    The slimcdk ActivationAction (tmc2209.enable/disable) fails to compile under
    ESPHome's 2026-04 TemplatableFn change — the bool `activate` field hits a
    static_assert ("Missing cg.templatable(...)"). Replace all four enable/disable
    calls with two helper scripts (motor_engage / motor_freewheel) built on the
    working CurrentsAction:
    - free-wheel → standstill_mode: freewheeling, hold_current: 0 mA
    - re-engage → standstill_mode: normal, hold_current: ${hold_current}
    Scripts have no delays, so script.execute runs them synchronously before the
    caller's next action (ordering vs set_target preserved). Docs updated.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
    [stepper-uart.yaml]
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2026-06-06 firmware: switchable homing_mode (contact | sensorless)
    Add a build-time homing_mode substitution so closed/open end detection can be
    the sensor-based hybrid or fully sensorless, selectable from window-opener.yaml.
    - contact (default): home CLOSED from the HA contact, OPEN by calibrated step
    count; StallGuard is only an obstruction backstop.
    - sensorless: no contact. Ram CLOSED at a gentle homing_current until StallGuard
    trips (do_home drops current then restores), and LEARN the OPEN end from the
    opening-direction stall.
    Mechanics:
    - New globals g_sensorless (from substitution) and g_full_stroke (runtime full
    stroke: fixed in contact, learned in sensorless). All motion math + the c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
    [stepper-uart.yaml]
2026-06-09 firmware: always re-engage motor currents before a move
    Fix "command accepted but motor silent": the TMC2209 could sit in a
    released / 0-current standstill state while g_freewheel read false (boot-time
    tmc2209.currents write not landing over UART, or a prior free-wheel session).
    move_to then set a target with no coil torque, so nothing moved and
    actual_current stayed 0 — diagnosed live over the API (cover position frozen,
    current 0; a free-wheel toggle ran motor_engage and the queued move executed).
    move_to now ALWAYS runs motor_engage before driving (skipped only while
    locked, where the lock clamp owns currents), instead of only when leaving
    free-wheel. One defensive UART write per comma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
    [stepper-uart.yaml]
2026-06-11 firmware: pin slimcdk component to b5f0e44 (was refresh:1d off master)
    Freeze the TMC2209 driver code to a specific commit for a reproducible
    baseline while debugging the tick-hook abort crash, instead of pulling master
    daily. b5f0e44 (2026-03-04) is master HEAD at pin time and is what the running
    firmware was already built against, so behavior is unchanged.
    Note: the component has not changed since March; the earlier compile break and
    deprecation warnings came from the ESPHome CORE moving (2026.x), which this pin
    does NOT cover. This is for reproducibility, not a confirmed crash fix.
    [stepper-uart.yaml]
2026-06-11 firmware: add manual closed/open calibration buttons
    Two template button entities:
    - "Set CLOSED home (0%) here" — report_position 0, mark homed.
    - "Set OPEN limit (100%) here" — capture current step count as g_full_stroke
    (guarded to current_position > 0), mark homed.
    Lets both ends be taught by jogging to them, with no contact sensor or
    StallGuard — useful for first calibration on the mounted window. Both stop any
    in-flight motion before capturing so the reading is stable.
    g_full_stroke is now restore_value: yes so a manual open-limit calibration
    survives a reboot (the absolute step count doesn't persist, but the scale
    does; initial_value still applies on the first boot after a f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
    [stepper-uart.yaml]
2026-06-11 firmware: microsteps 16->8 for real speed; g_full_stroke non-persistent
    The ESP32-C6 single-thread STEP generator tops out ~1100 steps/s (confirmed
    live: motor crawled at ~1.4 mm/s with max_speed 8000 — pinned at the ceiling,
    no accel curve). Drop microsteps 16->8 and steps_full_stroke 144000->72000 to
    match: half the pulses per mm -> ~2x real speed, interpolation keeps it smooth.
    Also revert g_full_stroke to restore_value: no. Persisting it fought the
    substitution: after this flash a restored old value (144000) would override the
    new 72000 and drive the open end 2x too far into the hard stop. steps_full_stroke
    is now authoritative every boot; the "Set OPEN limit" button is live-only
    cali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
    [stepper-uart.yaml]
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2026-06-11 firmware: add position sensors (usteps + mm) for open-travel calibration
    Two diagnostic template sensors exposing window_stepper.current_position in
    raw µsteps and in mm (50*microsteps µsteps/mm). Lets you read the true open
    count at the stop (jog there, or let a too-big steps_full_stroke stall-learn
    it) and bake the value into the steps_full_stroke substitution. These read an
    in-memory variable, not UART registers, so no step-generator starvation.
    [stepper-uart.yaml]
